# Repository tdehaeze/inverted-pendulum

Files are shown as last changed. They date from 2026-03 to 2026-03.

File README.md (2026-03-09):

# Inverted Pendulum

Active stabilization of an inverted pendulum on a cart, built from a recycled
3D printer (Alfawise U20). The system is controlled by a Teensy 4.1
microcontroller running a 1 kHz feedback loop, and monitored via a PyQt5 GUI.

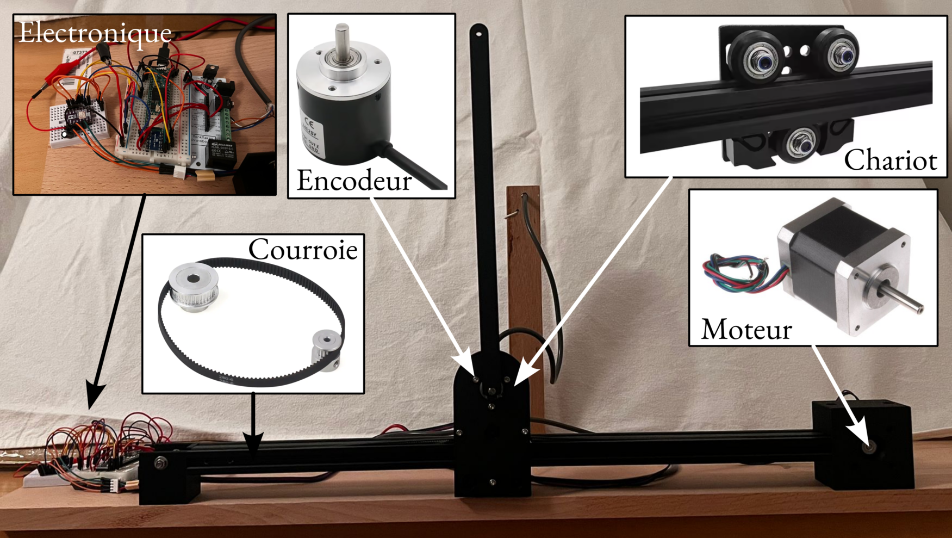
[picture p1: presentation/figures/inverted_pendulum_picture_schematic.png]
System overview


## Repository Structure

```
teensy/     Embedded firmware (PlatformIO / Arduino)
model/      Python simulation and control design
gui/        Real-time control interface (PyQt5)
tools/      Data capture and analysis scripts
data/       Recorded experiment CSV files
figs/       Generated figures
docs/       Hardware datasheets
```

## Hardware

| Component | Details |
|---|---|
| Microcontroller | Teensy 4.1 |
| Stepper motor | DRV8825 driver, 32 microsteps, 5 µm/step |
| Pendulum encoder | Quadrature, 4096 steps/rev → 0.088°/step |
| Cart travel | ±200 mm hard stop, ±160 mm soft limit |
| Control rate | 1 kHz (`IntervalTimer`) |

---

## 1 — Teensy Firmware

### Dependencies

- [PlatformIO](https://platformio.org/) (CLI or VS Code extension)
- Encoder library by Paul Stoffregen (declared in `teensy/platformio.ini`)

### Build and Flash

```bash
cd teensy/
pio run -e teensy41                # build only
pio run -e teensy41 -t upload      # build + flash
```

### Serial Monitor

```bash
pio device monitor                 # 115200 baud
```

### Serial Commands

Once the firmware is running, commands can be sent via the GUI or any serial
terminal at 115200 baud:

| Command | Description |
|---|---|
| `MOTOR ON` / `MOTOR OFF` | Enable / disable stepper motor |
| `FB ON` / `FB OFF` | Close / open feedback loop |
| `ZERO CART` | Reset cart position to 0 |
| `ZERO ENC` | Reset pendulum encoder to 0 |
| `VEL <mm/s>` | Open-loop cart velocity |
| `MODE P` / `MODE PD` / `MODE LQR` | Select controller |
| `SET KP <val>` | Proportional gain (SI units) |
| `SET KD <val>` | Derivative gain (SI units) |
| `SET K <k0> <k1> <k2> <k3>` | LQR gain vector [x, ẋ, φ, φ̇] |
| `SET THETA <deg>` | Pendulum angle setpoint |
| `SET X <mm>` | Cart position setpoint |

### Controllers (all gains in SI units)

- **P**: `u = -Kp · φ`
- **PD**: `u = -Kp · φ - Kd · φ̇`
- **LQR**: `u = -K · [x, ẋ, φ, φ̇]`

where `u` is cart acceleration [m/s²] and `φ = θ − π` is the deviation from
the upright position.

---

## 2 — GUI

### Setup (first time)

```bash
cd gui/
python -m venv .venv
source .venv/bin/activate
pip install PyQt5 pyqtgraph pyserial numpy scipy colorama
```

### Run

```bash
source gui/.venv/bin/activate
python gui/program.py
```

Connects to the Teensy at `/dev/ttyACM0`, 115200 baud. The interface provides:

- **Controller panel** — mode selection (P / PD / LQR), gain entry
- **Setpoints panel** — θ_ref and x_ref
- **Motor control** — enable/disable motor and feedback, zero buttons,
  open-loop velocity slider
- **Data panel** — save telemetry to CSV

---

## 3 — Model & Simulation

### Setup (first time)

```bash
cd model/
python -m venv .venv
source .venv/bin/activate
pip install numpy matplotlib scipy control
```

### Run

```bash
source model/.venv/bin/activate
python model/inverted_pendulum.py
```

Generates simulation figures in `figs/`: open-loop responses, P/PD stability
boundaries, LQR and LQG results.

### System Model

Linearized equations of motion around the upright position (φ = θ − π ≈ 0):

```
D · φ̈ + c · φ̇ − mgl · φ = ml · u
```

State-space form with **X = [x, ẋ, φ, φ̇]**, input **u = ẍ** [m/s²]:

```
Ẋ = A·X + B·u
```

Parameters identified from free-response measurement (`tools/fit.py`):

| Parameter | Symbol | Value |
|---|---|---|
| Pendulum mass | m | 0.1 kg |
| Pendulum length (half) | l | 0.326 m |
| Friction coefficient | c | 3.4 × 10⁻⁴ N·m·s/rad |

---

## 4 — Tools

All tools use the GUI virtual environment:

```bash
source gui/.venv/bin/activate
```

### Capture telemetry

```bash
python tools/capture.py                          # 10 s → data/data.csv
python tools/capture.py -d 30 -o data/run.csv   # 30 s to custom file
python tools/capture.py -d 10 -p /dev/ttyACM1   # custom port
```

### Fit model parameters

```bash
python tools/fit.py data/free_response.csv --mass 0.1
```

Fits pendulum length `l` and friction `c` to a free-response recording using
Nelder-Mead optimisation. Saves `figs/<name>_data.png` and
`figs/<name>_fit.png`.

Options: `--mass`, `--t-start`, `--l-init`, `--c-init`

### Plot experiment

```bash
python tools/plot_experiment.py data/run.csv
python tools/plot_experiment.py data/run.csv --ylim-phi 5 --ylim-x 100
python tools/plot_experiment.py data/run.csv --split --zero-at-feedback
python tools/plot_experiment.py data/run.csv --all --detrend-x --no-shading
```

Plots the last closed-loop segment of a CSV recording (φ and cart position).

| Option | Description |
|---|---|
| `--all` | Plot entire file instead of last segment |
| `--margin <s>` | Time margin before/after segment (default: 1 s) |
| `--margin-after <s>` | Override margin after segment |
| `--ylim-phi <deg>` | ±limit on φ axis |
| `--ylim-x <mm>` | ±limit on cart position axis |
| `--detrend-x` | Remove mean from cart position |
| `--no-shading` | Hide green feedback-on shading |
| `--split` | Save separate `_phi.png` and `_x.png` figures (half-width) |
| `--zero-at-feedback` | Set t = 0 at feedback start |

### Plot stability

```bash
python tools/plot_stability.py data/run.csv --duration 20
python tools/plot_stability.py data/run.csv --duration 30 --ylim-phi 3 --ylim-x 10
```

Plots the last N seconds of a recording to visualise closed-loop stability.

---

## 5 — Typical Workflow

### Initial setup

1. Flash the firmware: `cd teensy && pio run -e teensy41 -t upload`
2. Start the GUI: `source gui/.venv/bin/activate && python gui/program.py`
3. Enable the motor (**Motor ON**), zero the cart and encoder

### Identify model parameters

1. Place pendulum hanging freely (θ ≈ 0°)
2. Give it a small push and record 10–50 s of free oscillation:
   ```bash
   python tools/capture.py -d 50 -o data/free_response.csv
   ```
3. Fit the model:
   ```bash
   python tools/fit.py data/free_response.csv --mass <m_kg>
   ```
4. Update `PendulumParameters` in `model/inverted_pendulum.py` with the
   fitted values

### Tune and run a controller

1. In the GUI, set **MODE PD** and enter Kp / Kd
2. Bring the pendulum near upright and press **FB ON**
3. Save data with **Save CSV**, then analyse:
   ```bash
   python tools/plot_experiment.py data/<run>.csv --split --zero-at-feedback --ylim-phi 5
   ```

### LQR synthesis

```bash
source model/.venv/bin/activate
python model/inverted_pendulum.py   # prints K vector
```

Enter the resulting K in the GUI under **LQR gains**, switch to **MODE LQR**.

---

## 6 — Demonstrations

### System identification — free oscillation response

https://github.com/user-attachments/assets/c429f093-9673-4762-9016-3ae0847f1448

Free oscillation of the pendulum used to identify the model parameters (length $l$, friction coefficient $c$) via least-squares fitting.

---

### PD control — stabilization

https://github.com/user-attachments/assets/20660b4e-676f-49f9-a179-077e801f84ba

Pendulum stabilized at the upright position using a PD controller. The pendulum angle is regulated but the cart drifts over time.

---

### PD control — damping only

https://github.com/user-attachments/assets/50c5440a-8c1c-4f35-89b8-adac04f1c9ea

Controller acting primarily as a damper, slowing down the pendulum dynamics without full stabilization.

---

### LQR — low gain

https://github.com/user-attachments/assets/f3a342e8-8304-4135-925a-9110caccaa7a

LQR with low state weighting: the controller stabilizes the pendulum with slow, smooth corrections.

---

### LQR — high gain

https://github.com/user-attachments/assets/20061e29-bd0e-405f-b965-5c8c7497c029

LQR with higher gain: faster correction of angle and cart position deviations.

---

### LQR — higher gain

https://github.com/user-attachments/assets/9aa5e672-d7a8-477d-8541-99d07afa2d80

Wide view of the same higher-gain LQR configuration, showing simultaneous control of both angle and cart position.

---

### LQR — changing cart position setpoint

https://github.com/user-attachments/assets/6f5ab4ad-76a4-4d68-8fe5-9a155da7ca44

LQR controller tracking a step change in the cart position setpoint $x_\mathrm{ref}$, while keeping the pendulum upright.

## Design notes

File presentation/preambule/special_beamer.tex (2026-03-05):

%%%%%%%%%%%%%%%%%%%%%%%%%%%%%%%%%%%%%%%%%
% Beamer Presentation
% LaTeX Template
% Version 1.0 (10/11/12)
%
% This template has been downloaded from:
% http://www.LaTeXTemplates.com
%
% License:
% CC BY-NC-SA 3.0 (http://creativecommons.org/licenses/by-nc-sa/3.0/)
%
%%%%%%%%%%%%%%%%%%%%%%%%%%%%%%%%%%%%%%%%%

%----------------------------------------------------------------------------------------
%	PACKAGES AND THEMES
%----------------------------------------------------------------------------------------

\mode<presentation> {

% The Beamer class comes with a number of default slide themes
% which change the colors and layouts of slides. Below this is a list
% of all the themes, uncomment each in turn to see what they look like.

%\usetheme{default}
%\usetheme{AnnArbor}
%\usetheme{Antibes}
%\usetheme{Bergen}
%\usetheme{Berkeley}
%\usetheme{Berlin}
%\usetheme{Boadilla}
%\usetheme{CambridgeUS}
%\usetheme{Copenhagen}
%\usetheme{Darmstadt}
%\usetheme{Dresden}
%\usetheme{Frankfurt}
%\usetheme{Goettingen}
%\usetheme{Hannover}
%\usetheme{Ilmenau}
%\usetheme{JuanLesPins}
%\usetheme{Luebeck}
%\usetheme{Madrid}		
%\usetheme{Malmoe}
%\usetheme{Marburg}
%\usetheme{Montpellier}
%\usetheme{PaloAlto}
%\usetheme{Pittsburgh}
%\usetheme{Rochester}
%\usetheme{Singapore}
%\usetheme{Szeged}
\usetheme{Warsaw}

% As well as themes, the Beamer class has a number of color themes
% for any slide theme. Uncomment each of these in turn to see how it
% changes the colors of your current slide theme.

%\usecolortheme{albatross}
%\usecolortheme{beaver}
%\usecolortheme{beetle}
%\usecolortheme{crane}
%\usecolortheme{dolphin}
%\usecolortheme{dove}
%\usecolortheme{fly}
%\usecolortheme{lily}
%\usecolortheme{orchid}
%\usecolortheme{rose}
%\usecolortheme{seagull}
%\usecolortheme{seahorse}
\usecolortheme{whale}
%\usecolortheme{wolverine}

%\setbeamertemplate{footline} % To remove the footer line in all slides uncomment this line
%\setbeamertemplate{footline}[frame number] % To replace the footer line in all slides with a simple slide count uncomment this line

%\setbeamertemplate{navigation symbols}{} % To remove the navigation symbols from the bottom of all slides uncomment this line

% \setbeamercovered{transparent} % Fait apparaître les animations en grisé (utile pour la conception, mais peut être commenté lors de la remise du document final)

% Pour utiliser une police à empattements partout
\usefonttheme{serif}

% Pour rajouter la numérotation des frames dans les pieds de page
\newcommand*\oldmacro{}%
\let\oldmacro\insertshorttitle%
\renewcommand*\insertshorttitle{%
  \oldmacro\hfill%
  \insertframenumber\,/\,\inserttotalframenumber}

}

\usepackage{graphicx} % Allows including images
\usepackage{booktabs} % Allows the use of \toprule, \midrule and \bottomrule in tables

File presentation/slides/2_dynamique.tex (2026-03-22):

\section{Étude de la dynamique du Pendule Inversé}

\begin{frame}
\frametitle{Étude de la dynamique}
\framesubtitle{Présentation du système}

\begin{figure}
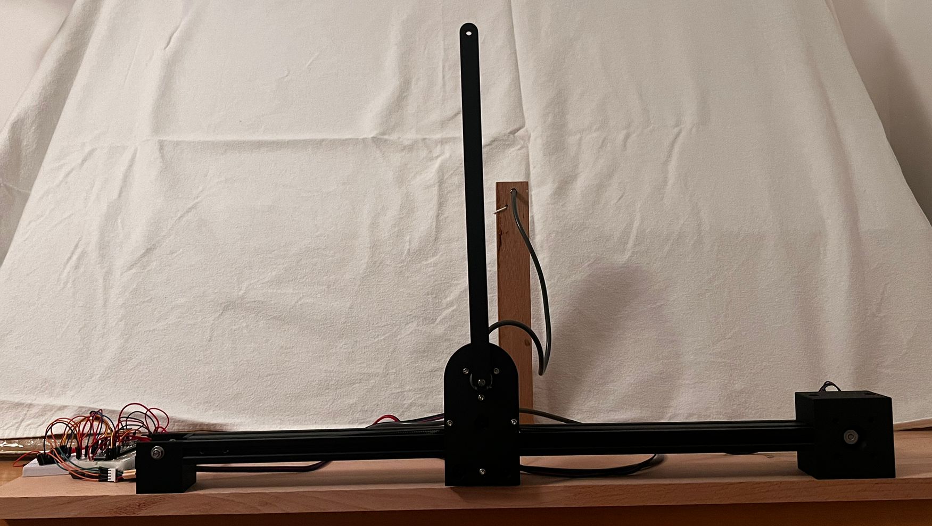
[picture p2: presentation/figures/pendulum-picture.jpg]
    \only<1>{}%
    \only<2>{}
\end{figure}

\end{frame}

%%%%%%%%%%%%%%%%%%%%%%%%%%%%%%%%%%%%%%%%%%%%%%%%

\begin{frame}
\frametitle{Étude de la dynamique}
\framesubtitle{Modèle et Équations de la dynamique}

\begin{columns}[T]

%--- Colonne gauche : schéma ---
\begin{column}{0.4\textwidth}
\begin{center}
\begin{tikzpicture}[>=Stealth, scale=0.8]

  % Ground
  \fill[pattern=north east lines, pattern color=gray!60] (-1.5,-0.18) rectangle (1.5,0);
  \draw[thick] (-1.5,0) -- (1.5,0);

  % Wheels
  \draw[thick, fill=white] (-0.45, 0.15) circle [radius=0.15];
  \draw[thick, fill=white] ( 0.45, 0.15) circle [radius=0.15];

  % Cart body
  \draw[thick, fill=gray!20, rounded corners=3pt]
    (-0.8, 0.15) rectangle (0.8, 0.75);

  % Pivot
  \coordinate (O) at (0, 0.75);
  \fill (O) circle [radius=0.1];

  % Pendulum (theta = 150 deg from downward, 30 deg from upright)
  \coordinate (tip) at ($(O) + ({0.5*3.0}, {0.866*3.0})$);

  % Dashed verticals
  \draw[dashed, gray] (O) -- ++(0,  3.5);
  \draw[dashed, gray] (O) -- ++(0, -0.9);

  % Angle arc (CCW from downward to rod, through right side)
    \draw[->, thick, red!60!black] ($(O)+(-90:0.7)$) arc[start angle=-90, end angle=60, radius=0.7] node[near end, right] {$\theta$};

  % Pendulum rod
  \draw[line width=2pt] (O) -- node[midway, right=6pt] {$m$} (tip);

  % Length arrow
  \draw[<->, thin]
    ($(O)   + ({-0.866*0.35}, {0.5*0.35})$)
    -- node[left=2pt] {$l$}
    ($(tip) + ({-0.866*0.35}, {0.5*0.35})$);

  % Tip dot
  \fill (tip) circle [radius=0.05];

  % Acceleration arrow
  \draw[->, thick, blue!60!black]
    (0.85, 0.44) -- ++(1.0, 0) node[right] {$u = \ddot{x}$};

\end{tikzpicture}
\end{center}
\end{column}

%--- Colonne droite : équations ---
\begin{column}{0.58\textwidth}
  \vspace{0.5cm}
  \textbf{Équation du mouvement :}
  \begin{equation*}
      \frac{1}{3}ml^2\,\ddot{\theta} + c\,\dot{\theta} + \underbrace{mgl\sin\theta + ml\cos\theta\cdot u}_{\text{non linéaire}} = 0
  \end{equation*}

    \only<2>{%

    \vfill
    \begin{center}
    \begin{tcolorbox}[
        width=0.9\linewidth,
        colback=blue!5,
        colframe=blue!50!black,
        arc=4pt,
        boxrule=1pt,
        fontupper=\large
    ]
        Linéarisation pour étude de la dynamique et contrôle
    \end{tcolorbox}
    \end{center}
    \vfill
    }%
\end{column}

\end{columns}

\end{frame}

%%%%%%%%%%%%%%%%%%%%%%%%%%%%%%%%%%%%%%%%%%%%%%%%

\begin{frame}
\frametitle{Étude de la dynamique}
\framesubtitle{Linéarisations et Réponses du système}

\begin{columns}[T]

\begin{column}{0.48\textwidth}
  \uncover<1->{%
  \centering\textbf{Position basse} ($\theta \approx 0$)
  \begin{equation*}
      \frac{1}{3}ml^2\,\ddot{\theta} + c\,\dot{\theta} + mgl\,\theta = -mlu
  \end{equation*}
  $\Rightarrow$ Oscillations amorties

  \begin{figure}
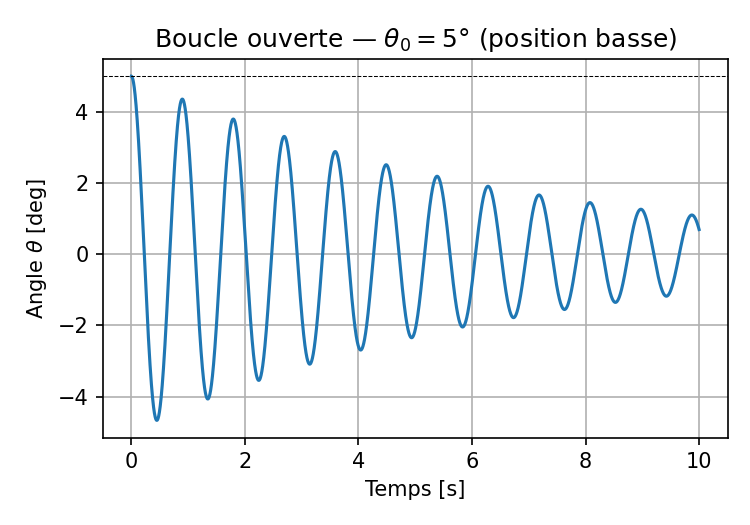
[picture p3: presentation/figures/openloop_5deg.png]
      
  \end{figure}
  }%
\end{column}

\begin{column}{0.48\textwidth}
  \uncover<2->{%
  \centering\textbf{Position haute} ($\varphi = \theta - \pi \approx 0$)
  \begin{equation*}
      \frac{1}{3}ml^2\,\ddot{\varphi} + c\,\dot{\varphi} - mgl\,\varphi = mlu
  \end{equation*}
  $\Rightarrow$ Divergence exponentielle

  \begin{figure}
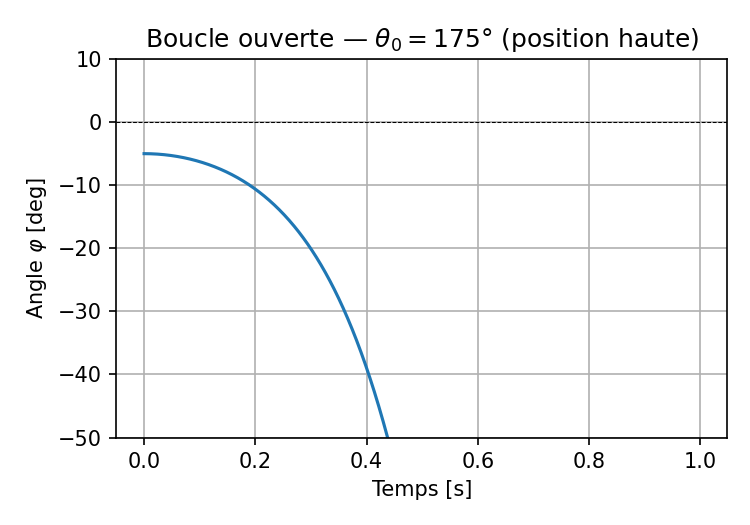
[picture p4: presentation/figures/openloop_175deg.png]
      
  \end{figure}
  }%
\end{column}

\end{columns}

\end{frame}

%%%%%%%%%%%%%%%%%%%%%%%%%%%%%%%%%%%%%%%%%%%%%%%%

\begin{frame}
\frametitle{Étude de la dynamique}
\framesubtitle{Comparaison modèle / expérience}

\begin{center}
\begin{tikzpicture}[>=Stealth,
    box/.style={draw, rounded corners=4pt, fill=blue!8, text width=2.4cm,
                align=center, minimum height=1.2cm, font=\small},
    arr/.style={->, thick, blue!60!black}
  ]

  \node[box] (meas) {Mesure de la\\réponse\\expérimentale};
  \uncover<2->{%
      \node[box, right=1.4cm of meas] (opt) {Optimisation\\des paramètres\\du modèle (Python)};
    \node[box, right=1.0cm of opt]  (res) {Paramètres\\identifiés\\$l,\ c$};
    \draw[arr] (meas) --node[midway, above]{Données}node[midway, below]{$m = 30\,g$} (opt);
    \draw[arr] (opt)  -- (res);
  }

\end{tikzpicture}
\end{center}

\vspace{0.2cm}

\begin{figure}
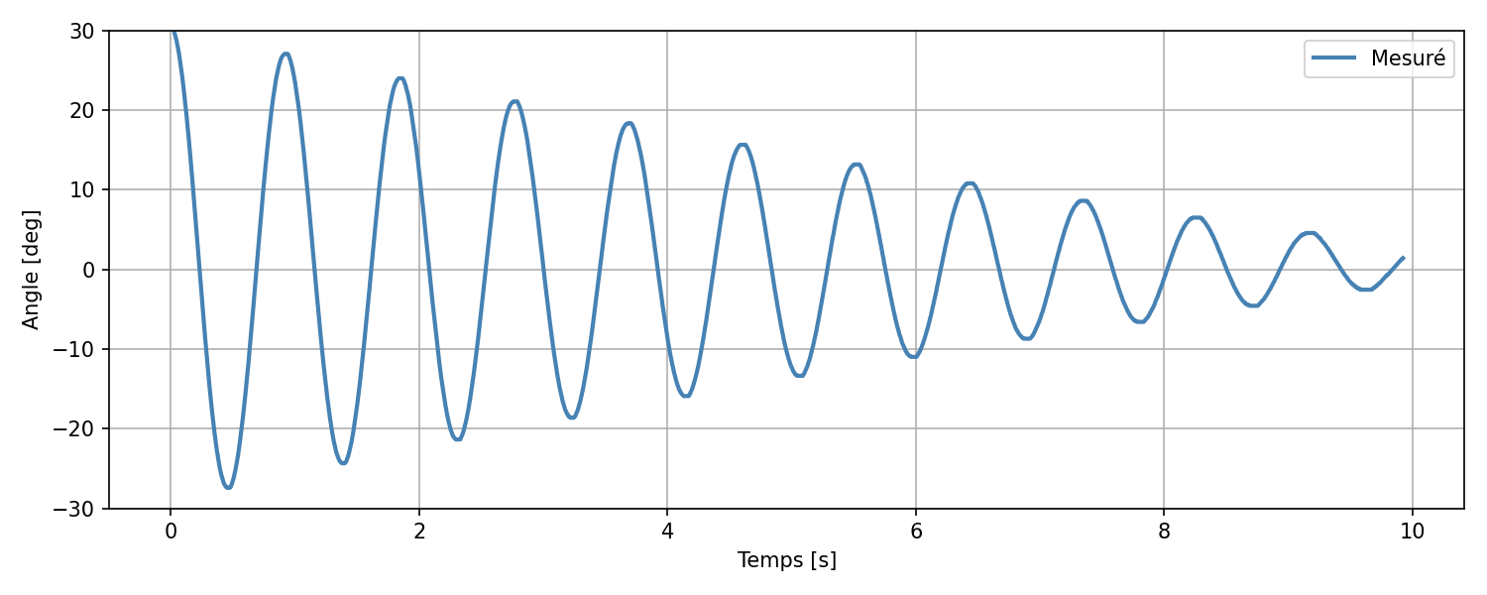
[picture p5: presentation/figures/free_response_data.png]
  \only<1>{}%
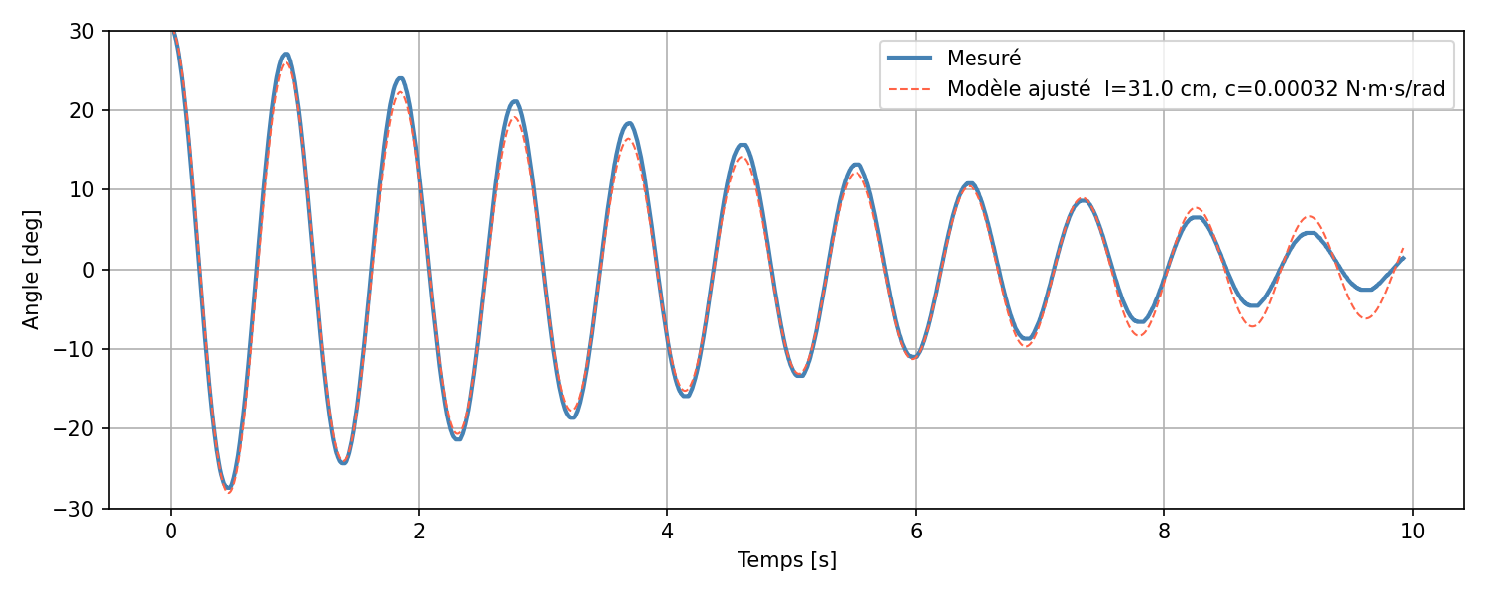
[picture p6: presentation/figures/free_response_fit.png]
  \only<2>{}%
\end{figure}

\end{frame}

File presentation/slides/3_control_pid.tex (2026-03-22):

% Le titre de la partie
\section{Stabilisation de la dynamique par contrôle PD}

%%%%%%%%%%%%%%%%%%%%%%%%%%%%%%%%%%%%%%%%%%%%%%%%

\begin{frame}
\frametitle{Contrôle PD}
\framesubtitle{Schéma block du contrôle du pendule inversé}

\begin{center}
\begin{tikzpicture}[>=Stealth, auto,
    block/.style={draw, rectangle, rounded corners=3pt, fill=blue!8,
                  minimum height=1.0cm, minimum width=2.2cm,
                  align=center, font=\small},
    sum/.style  ={draw, circle, minimum size=0.65cm, inner sep=0pt},
    node distance=0pt
  ]

  % Nodes
  \node[sum] (sum) {};
  \node[block, right=1.2cm of sum] (pd)    {Contrôleur\\PD};
  \node[block, right=1.8cm of pd]  (plant) {Pendule\\inversé};

  % Summing junction +/-
  \node[font=\footnotesize, below left=2pt and 2pt of sum] {$-$};

  % Input: theta_ref
  \draw[->] (sum.west) ++(-1.5,0) node[above right] {$\theta_\mathrm{ref} = \pi$} -- (sum.west);

  % sum -> PD
    \draw[->] (sum.east) -- node[midway, above] {$\varepsilon_\theta(t)$} (pd.west);

  % PD -> plant
    \draw[->] (pd.east) -- node[midway, above] {$u(t) = \ddot{x}(t)$} (plant.west);

  % plant -> output
    \draw[->] (plant.east) node[above right] {$\theta(t)$} -| ++(1.0, -1.0) -| (sum.south);
\end{tikzpicture}
\end{center}

\vspace{0.3cm}

\[
  u(t) = \underbrace{k_p \cdot \varepsilon_\theta(t)}_{\text{Proportionnel}}
        + \underbrace{k_d \cdot \frac{\mathrm{d} \varepsilon_\theta(t)}{\mathrm{d} t}}_{\text{Dérivé}}
\]

\end{frame}

%%%%%%%%%%%%%%%%%%%%%%%%%%%%%%%%%%%%%%%%%%%%%%%%

\begin{frame}
\frametitle{Contrôle PD}
\framesubtitle{Contrôleur Proportionnel}

Avec $u = -k_p\,\varphi$, l'équation linéarisée devient :
\[
    \frac{1}{3}ml^2\,\ddot{\varphi} + c\,\dot{\varphi} + (ml\,k_p - mgl)\,\varphi = 0
\]
    Stable si $\Delta = c^2 - 4 \frac{1}{3}ml^2 \cdot (ml\,k_p - mgl) > 0$, donc si $k_p > k_{p,c}$, avec
    \[
    k_{p,c} = g + \frac{3 c^2}{4 m^2l^3} \approx 9.8
\]

% \vspace{0.2cm}

\begin{columns}[T]
  \begin{column}{0.48\textwidth}
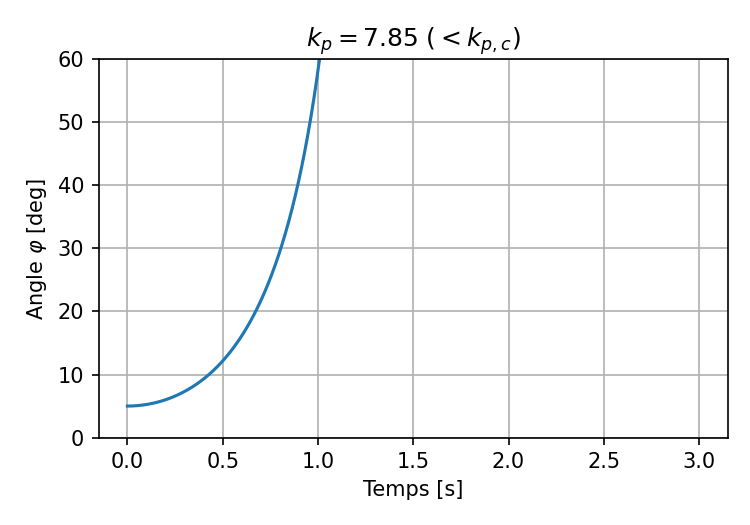
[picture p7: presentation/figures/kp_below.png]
    
  \end{column}
  \begin{column}{0.48\textwidth}
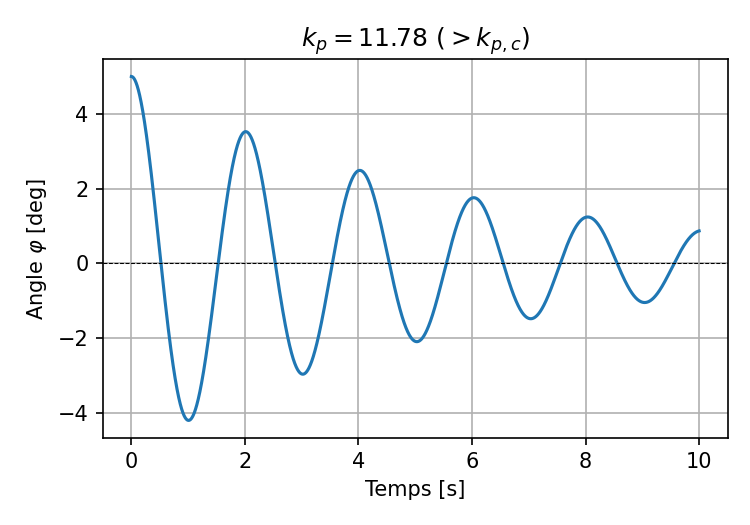
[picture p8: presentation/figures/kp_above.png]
    
  \end{column}
\end{columns}

\end{frame}

%%%%%%%%%%%%%%%%%%%%%%%%%%%%%%%%%%%%%%%%%%%%%%%%

\begin{frame}
\frametitle{Contrôle PD}
\framesubtitle{Contrôleur Dérivatif}

% Expliquer comment le contrôleur derivatif modifie la dynamique du système: ça ajoute de l'amortissement.
% Ca peut être important pour le confort sur un segway par exemple.

Avec $u = -k_p\,\varphi - k_d\,\dot{\varphi}$, l'équation linéarisée devient :
\[
    \frac{1}{3}ml^2\,\ddot{\varphi} + (c + ml\,k_d)\,\dot{\varphi} + (ml\,k_p - mgl)\,\varphi = 0
\]
Amortissement critique:
    \[
    k_{d,c} = \frac{1}{ml}\!\left(2\sqrt{\frac{1}{3}ml^2\,(ml\,k_p - mgl)} - c\right) \approx 1.2
\]

\begin{figure}
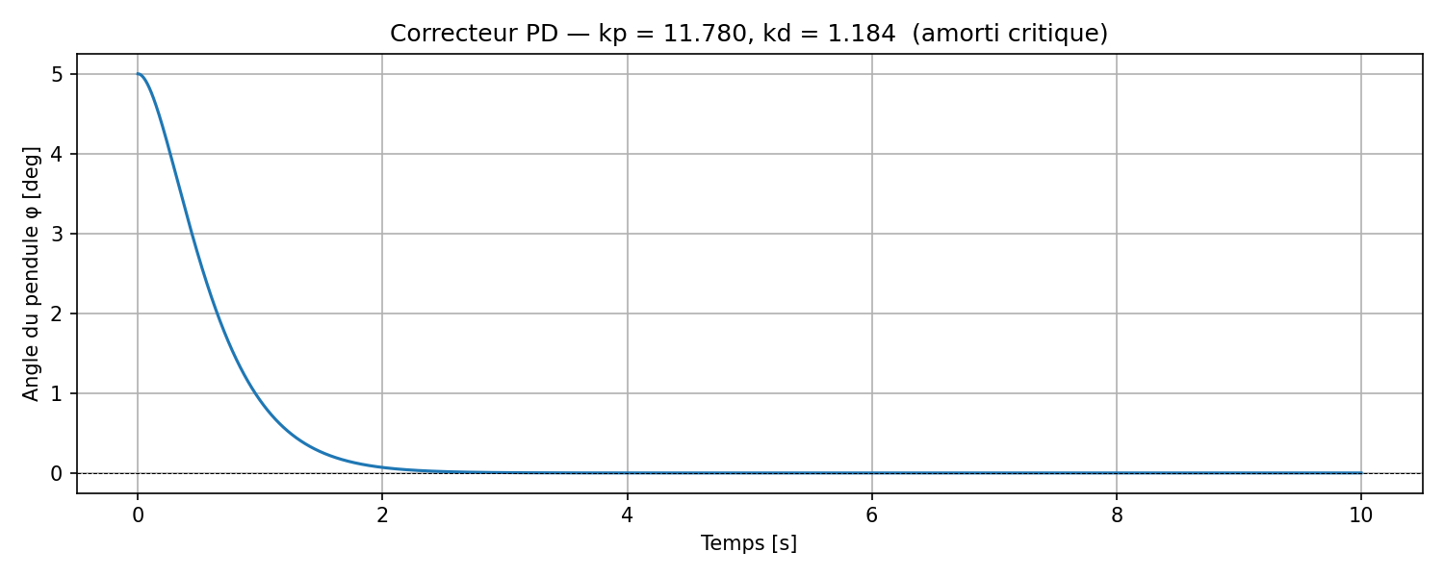
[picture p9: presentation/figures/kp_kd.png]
    
\end{figure}

\end{frame}

%%%%%%%%%%%%%%%%%%%%%%%%%%%%%%%%%%%%%%%%%%%%%%%%

\begin{frame}
\frametitle{Contrôle PD}
\framesubtitle{Résultats expérimentaux}

\begin{columns}[T]
  \begin{column}{0.48\textwidth}
    % Steps 1-2: experimental plots
    \uncover<1->{%
      {\scriptsize Résultats expérimentaux — $k_p = 12$, $k_d = 1$}\\
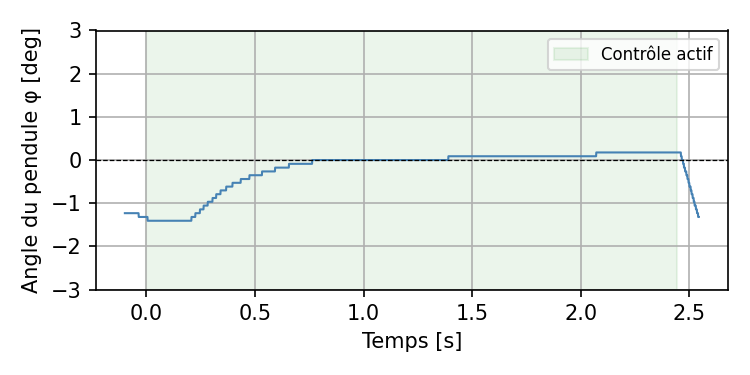
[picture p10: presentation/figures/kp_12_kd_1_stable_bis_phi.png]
      \\[2pt]
      \uncover<2->{%
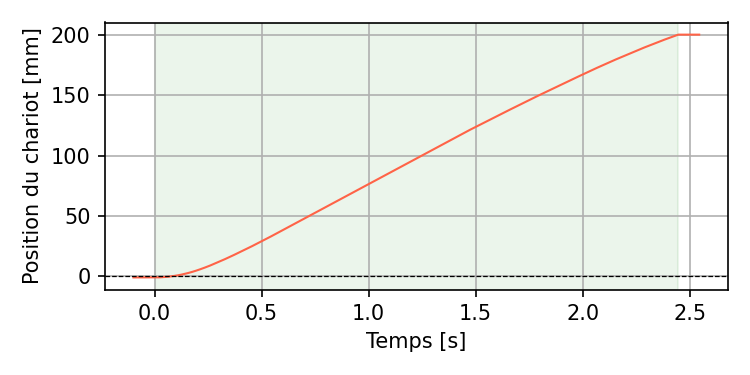
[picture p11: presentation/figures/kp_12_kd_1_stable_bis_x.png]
          %
      }%
    }%
  \end{column}
  \begin{column}{0.48\textwidth}
    % Steps 3-7: photos
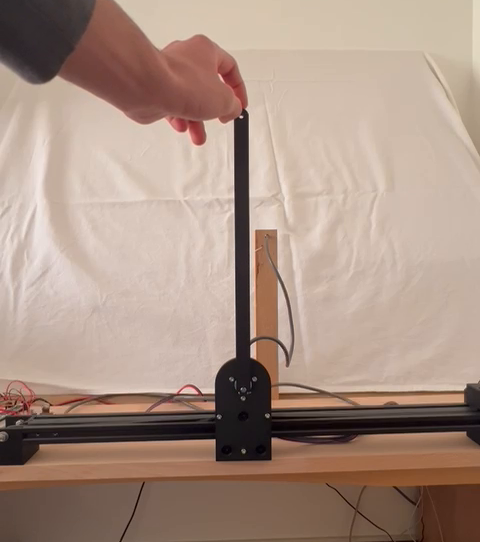
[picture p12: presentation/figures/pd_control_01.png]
    \only<3>{}%
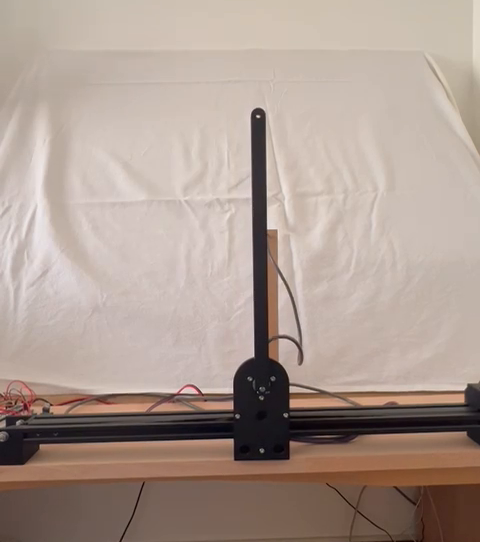
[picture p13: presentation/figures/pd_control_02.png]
    \only<4>{}%
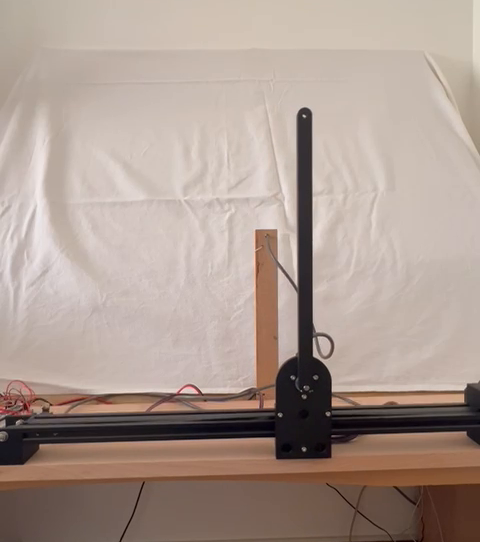
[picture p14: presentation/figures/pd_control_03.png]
    \only<5>{}%
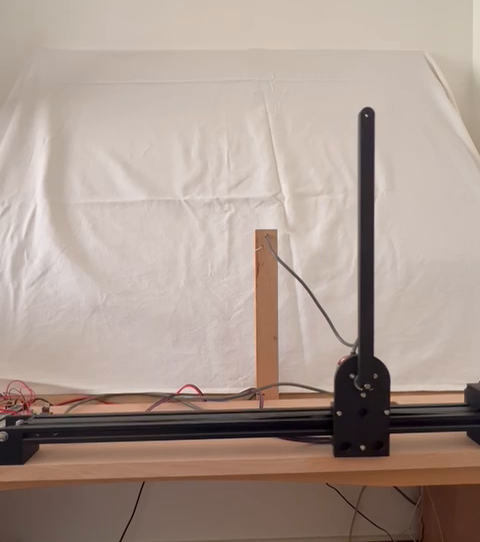
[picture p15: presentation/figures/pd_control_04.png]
    \only<6>{}%
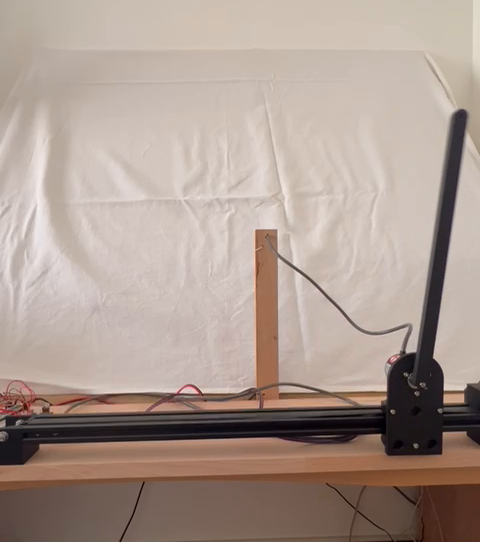
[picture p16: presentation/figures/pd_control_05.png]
    \only<7>{}%
    % Step 8: simulation
    \only<8>{%
        Même comportement en simulation:
        $\phi$ est correctement stabilisé, mais le chariot n'est pas stable.

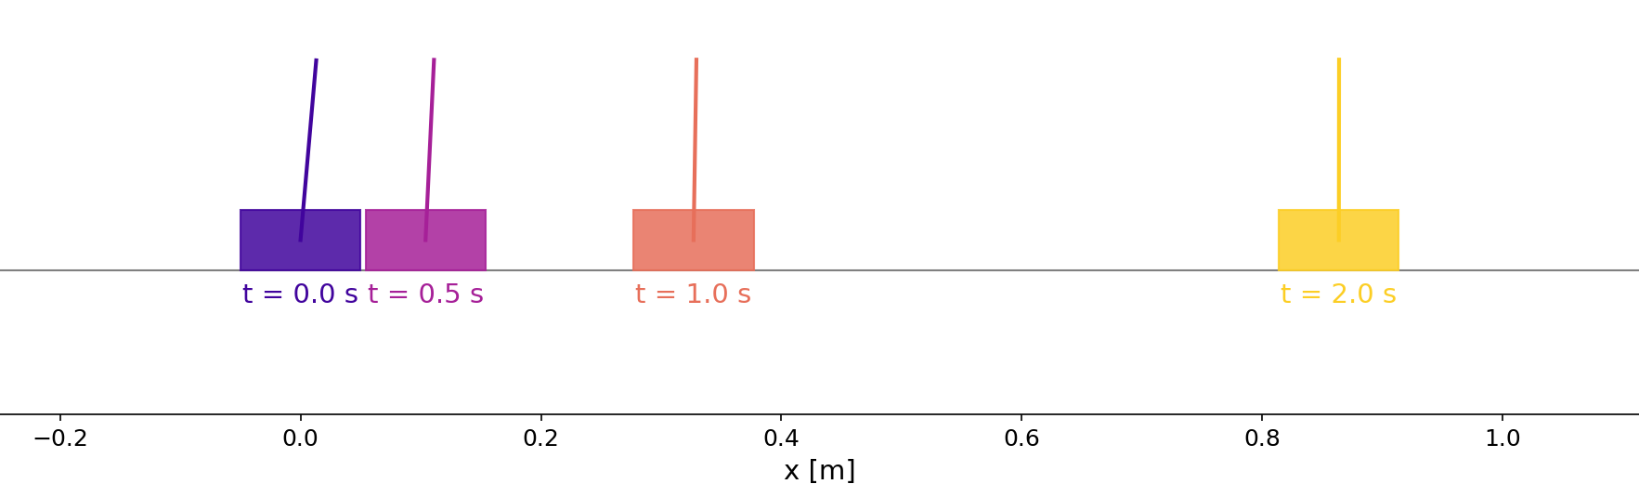
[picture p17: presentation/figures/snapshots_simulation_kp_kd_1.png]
        \\[2pt]
        {\scriptsize Résultats de simulation — $k_p = 12$, $k_d = 1$}

        \vspace{1em}

        Pour contrôler à la fois $\phi$ et $x$, le contrôleur PD n'est pas adapté.
    }%
  \end{column}
\end{columns}

\end{frame}

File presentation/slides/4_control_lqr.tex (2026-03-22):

\section{Stabilisation de la dynamique par contrôle LQ}

%%%%%%%%%%%%%%%%%%%%%%%%%%%%%%%%%%%%%%%%%%%%%%%%

\begin{frame}
\frametitle{Contrôle LQ}
\framesubtitle{Modèle d'état — Commande par retour d'état}

Modèle par représentation d'états:
\[
    \mathbf{X} =
    \begin{pmatrix} x \\ \dot{x} \\ \varphi \\ \dot{\varphi} \end{pmatrix}, \quad
        \dot{\mathbf{X}} = A\mathbf{X} + B u, \quad
        A = \begin{pmatrix}
            0 & 1 & 0 & 0 \\
            0 & 0 & 0 & 0 \\
            0 & 0 & 0 & 1 \\
            0 & 0 & \tfrac{3g}{l} & -\tfrac{3c}{ml^2}
        \end{pmatrix}, \quad
        B = \begin{pmatrix} 0 \\ 1 \\ 0 \\ \tfrac{3}{l} \end{pmatrix}
        \]

\vspace{1em}

Commande par retour d'état:

\vspace{1em}

\begin{tikzpicture}[>=Stealth, auto,
    block/.style={draw, rectangle, rounded corners=3pt, fill=blue!8,
                  minimum height=0.9cm, minimum width=2.0cm,
                  align=center, font=\small},
    sum/.style={draw, circle, minimum size=0.6cm, inner sep=0pt},
    node distance=0pt
  ]
  \node[sum] (sum) {};
  \node[font=\footnotesize, below left=0pt of sum] {$-$};
  \node[block, right=1.0cm of sum] (K) {$\mathbf{K}$};
  \node[block, right=1.0cm of K]   (plant) {Pendule\\inversé};

  % X_ref input
  \draw[->] (sum.west) ++(-1.2,0) node[above right] {$\mathbf{X}_\mathrm{ref}$} -- (sum.west);

  % sum -> K
  \draw[->] (sum.east) -- (K.west);

  % K -> plant
  \draw[->] (K.east) -- node[midway, above] {$u(t)$} (plant.west);

  % plant output + feedback
  \draw[->] (plant.east) node[above right] {$\mathbf{X}(t)$} -| ++(0.7,-1.0) -| (sum.south);
\end{tikzpicture}

\vspace{0.3cm}
\[
  u(t) = \mathbf{K}\,\bigl(\mathbf{X}_\mathrm{ref} - \mathbf{X}(t)\bigr), \quad
  \mathbf{K} = \begin{bmatrix} k_x & k_{\dot x} & k_\varphi & k_{\dot\varphi} \end{bmatrix}
\]

\end{frame}

%%%%%%%%%%%%%%%%%%%%%%%%%%%%%%%%%%%%%%%%%%%%%%%%

\begin{frame}
\frametitle{Contrôle LQ}
\framesubtitle{Choix de la matrice de retour d'état}

Minimisation d'un critère quadratique :
\[
  J = \int_0^\infty \!\bigl(\mathbf{X}^\top Q\,\mathbf{X} + u^\top R\,u\bigr)\,\mathrm{d}t
\]
\begin{itemize}
  \item $Q \succeq 0$ pondère les états: $Q = \mathrm{diag}(q_x,\, q_{\dot x},\, q_\varphi,\, q_{\dot\varphi})$
  \item $R > 0$ pondère l'effort de commande
\end{itemize}

\vspace{0.3cm}
$\mathbf{K}$ est obtenu par résolution de l'équation algébrique de Riccati :
\[
  A^\top P + PA - PBR^{-1}B^\top P + Q = 0
  \ \Longrightarrow\ 
  \boxed{\mathbf{K} = R^{-1}B^\top P}
\]

\vspace{1em}

\textbf{Exemple} $q_x = 100$, $q_\varphi = 1$, $R = 1$ $\Longrightarrow$ $\mathbf{K} = \begin{bmatrix} -10.0 & -8.7 & 46.9 & 9.8 \end{bmatrix}$

\end{frame}

%%%%%%%%%%%%%%%%%%%%%%%%%%%%%%%%%%%%%%%%%%%%%%%%

\begin{frame}
\frametitle{Contrôle LQ}
\framesubtitle{Simulation}

\begin{columns}[T]
  \begin{column}{0.5\textwidth}
    \centering
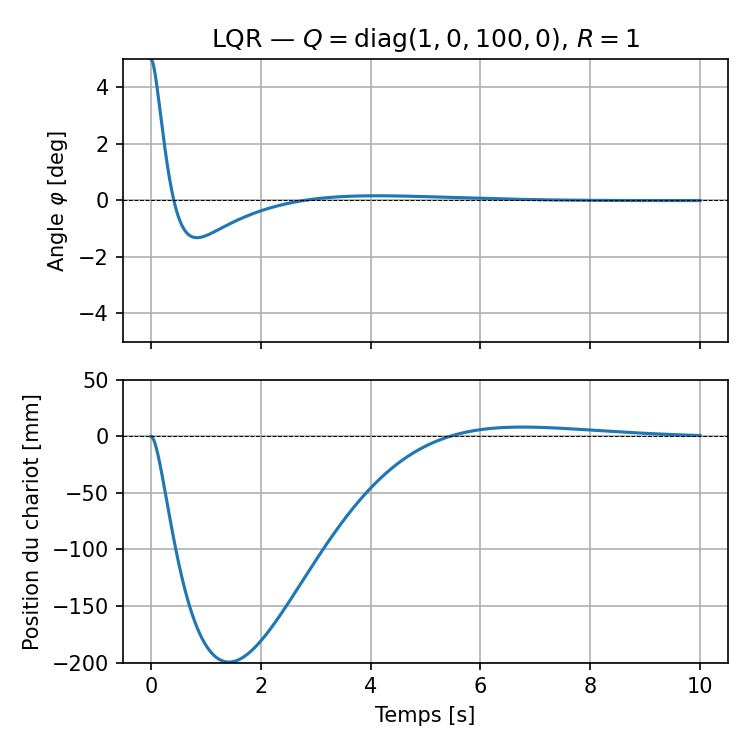
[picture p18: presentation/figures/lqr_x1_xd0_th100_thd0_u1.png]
    \\[2pt]
    {\scriptsize Pondération forte sur $\varphi$: $q_x = 1$, $q_\varphi = 100$}
  \end{column}
  \begin{column}{0.5\textwidth}
    \centering
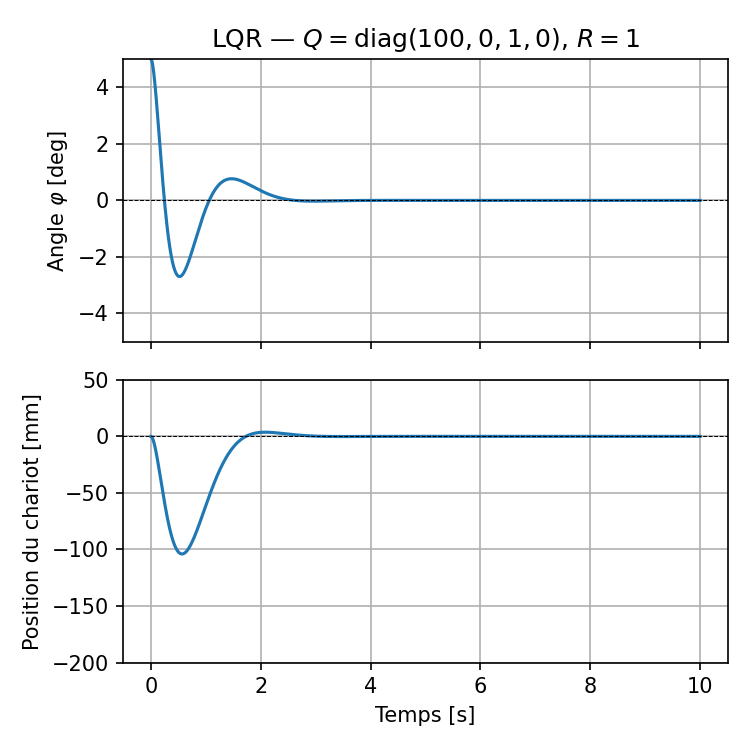
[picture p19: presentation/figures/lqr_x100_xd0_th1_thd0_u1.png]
    \\[2pt]
    {\scriptsize Pondération forte sur $x$: $q_x = 100$, $q_\varphi = 1$}
  \end{column}
\end{columns}

\end{frame}

%%%%%%%%%%%%%%%%%%%%%%%%%%%%%%%%%%%%%%%%%%%%%%%%

\begin{frame}
\frametitle{Contrôle LQ}
\framesubtitle{Résultats Expérimentaux}
\begin{columns}[T]
  \begin{column}{0.7\textwidth}
    \begin{figure}
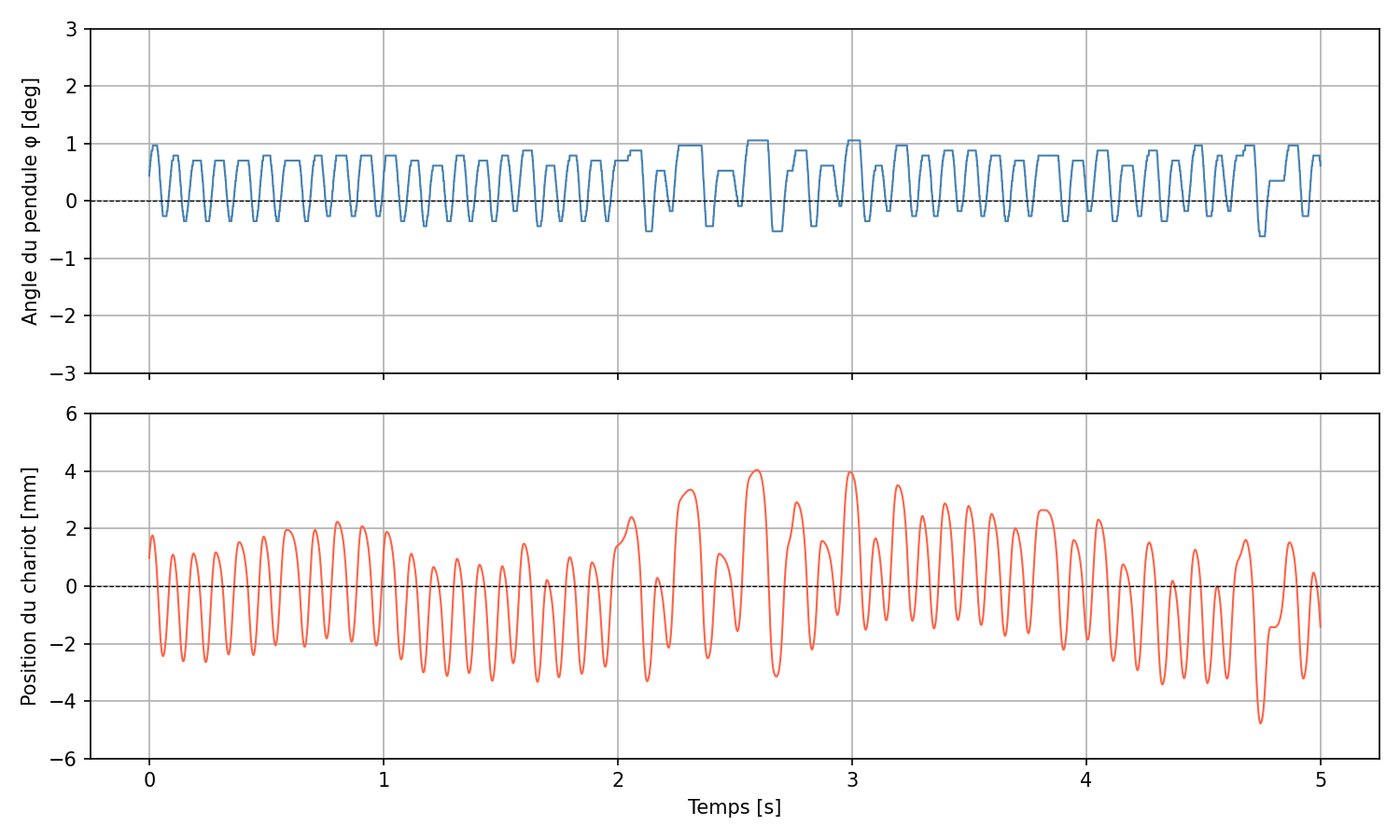
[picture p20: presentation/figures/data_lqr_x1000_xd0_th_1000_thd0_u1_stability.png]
        \\[2pt]
        
        {\scriptsize $\mathbf{K} = [-31.6\ -23.1\ 92.8\ 18.3]$, stabilité observée de $\pm 1\,\text{deg}$, $\pm 4\,mm$}
    \end{figure}
  \end{column}
  \begin{column}{0.3\textwidth}
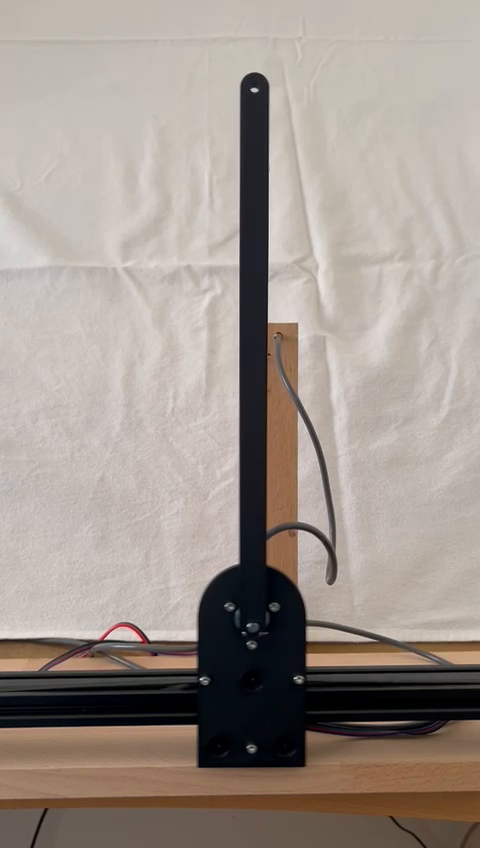
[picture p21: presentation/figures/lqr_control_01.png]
    \only<2>{}%
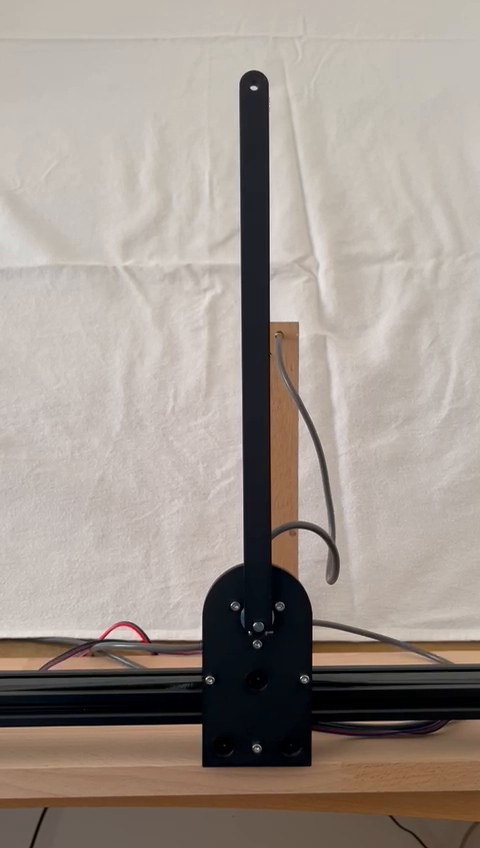
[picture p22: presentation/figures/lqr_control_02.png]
    \only<3>{}%
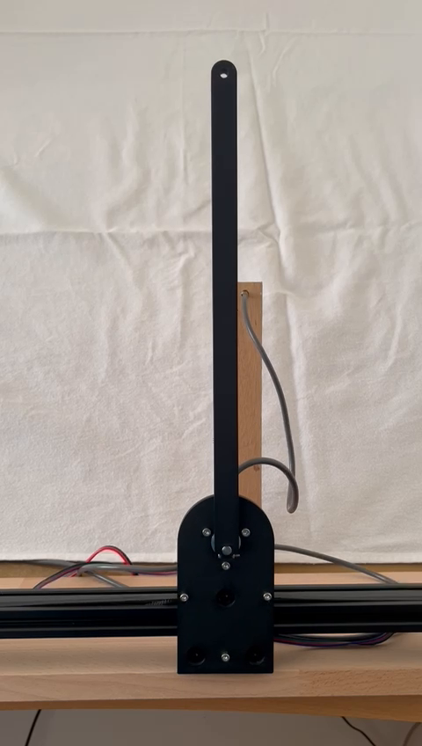
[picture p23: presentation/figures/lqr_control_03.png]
    \only<4>{}%
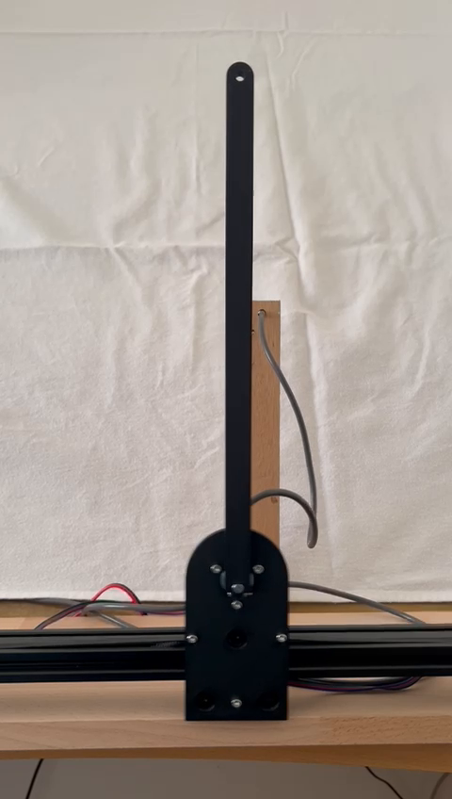
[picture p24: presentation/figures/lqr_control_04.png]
    \only<5>{}%
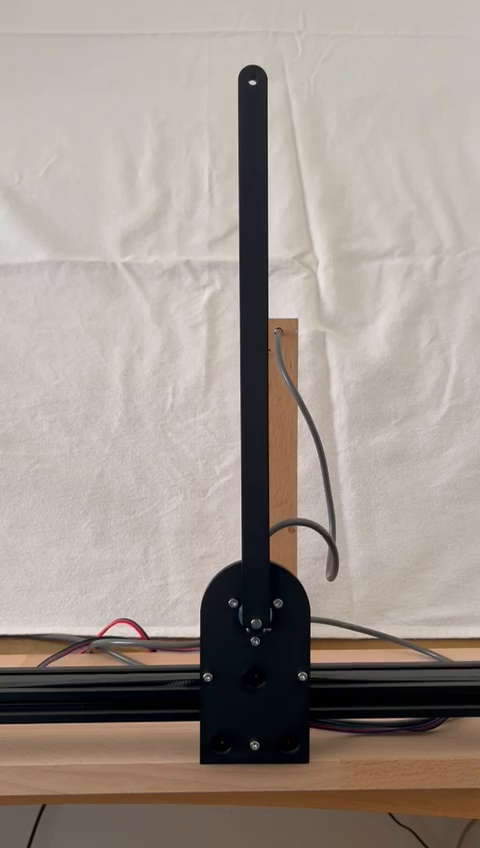
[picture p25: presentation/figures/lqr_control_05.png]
    \only<6>{}%
  \end{column}
\end{columns}
\end{frame}

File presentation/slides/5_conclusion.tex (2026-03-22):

% Le titre de la partie
\section{Conclusion}

%%%%%%%%%%%%%%%%%%%%%%%%%%%%%%%%%%%%%%%%%%%%%%%%
% Première diapo avec un exemple de tableau
%%%%%%%%%%%%%%%%%%%%%%%%%%%%%%%%%%%%%%%%%%%%%%%%
\begin{frame}
\frametitle{Conclusion}

\textbf{Bilan}
\begin{itemize}
  \item Pendule inversé sur chariot comme support d'étude du contrôle actif d'une dynamique instable
  \item Deux stratégies de contrôle comparées :
  \begin{itemize}
    \item \textbf{PD} — intuitif, paramètres à sens physique clair (gain, amortissement), mais ne stabilise pas la position du chariot
    \item \textbf{LQR} — optimal au sens d'un critère quadratique, s'appuie sur un modèle linéarisé, contrôle simultané de $\varphi$ et $x$
  \end{itemize}
\end{itemize}

\vspace{0.4cm}

\textbf{Perspectives}
\begin{itemize}
  \item \textbf{LQG} — ajout d'un filtre de Kalman pour l'estimation des états bruités ($\dot{x}$, $\dot{\varphi}$) ; extension naturelle du LQR
  \item \textbf{MPC} (commande prédictive) — optimisation sur un horizon glissant, permet de prendre en compte explicitement certaines contraintes physiques
\end{itemize}

\end{frame}

\begin{frame}[allowframebreaks]{Références}
  \printbibliography[heading=none]
\end{frame}

%%%%%%%%%%%%%%%%%%%%%%%%%%%%%%%%%%%%%%%%%%%%%%%%
% SLIDES DE BACKUP
%%%%%%%%%%%%%%%%%%%%%%%%%%%%%%%%%%%%%%%%%%%%%%%%

\appendix

\begin{frame}
\frametitle{Annexe — Matériel}
\framesubtitle{Récupération d'une imprimante 3D Alfawise U20}

\begin{center}
    
\end{center}

\end{frame}

%%%%%%%%%%%%%%%%%%%%%%%%%%%%%%%%%%%%%%%%%%%%%%%%

\begin{frame}
\frametitle{Annexe — Identification du modèle}
\framesubtitle{Réponse libre — masse 100\,g}

\begin{center}
    
\end{center}

\vspace{0.2cm}
{\small
Avec une masse plus importante, la friction est négligeable devant l'inertie :
le modèle linéarisé reproduit fidèlement la réponse libre expérimentale.
}

\end{frame}

%%%%%%%%%%%%%%%%%%%%%%%%%%%%%%%%%%%%%%%%%%%%%%%%

\begin{frame}
\frametitle{Annexe — Équivalence LQR / PD}
\framesubtitle{Le LQR comme double correcteur PD}

\begin{center}
\begin{tikzpicture}[>=Stealth,
    block/.style={draw, rectangle, rounded corners=3pt, fill=blue!8,
                  minimum height=0.85cm, minimum width=1.7cm,
                  align=center, font=\small},
    plant/.style={draw, rectangle, rounded corners=3pt, fill=blue!8,
                  minimum height=2.1cm, minimum width=1.7cm,
                  align=center, font=\small},
    sum/.style={draw, circle, minimum size=0.55cm, inner sep=0pt},
  ]

  \node[sum]   (sum_phi) at (0,   0.85) {};
  \node[sum]   (sum_x)   at (0,  -0.85) {};
  \node[block] (pd_phi)  at (2.3,  0.85) {PD$_\varphi$};
  \node[block] (pd_x)    at (2.3, -0.85) {PD$_x$};
  \node[sum]   (sum_u)   at (4.0,  0)    {};
  \node[plant] (plant)   at (6.0,  0)    {Pendule\\inversé};

  % +/- labels
  \node[font=\scriptsize, above left=-5pt and 2pt of sum_phi] {$+$};
  \node[font=\scriptsize, above left=2pt and -5pt of sum_phi] {$-$};
  \node[font=\scriptsize, above left=-5pt and 2pt of sum_x] {$+$};
  \node[font=\scriptsize, below left=2pt and -5pt of sum_x]   {$-$};
  \node[font=\scriptsize, above left=2pt and -5pt of sum_u]   {$+$};
  \node[font=\scriptsize, below left=2pt and -5pt of sum_u]   {$+$};

  % References
  \draw[->] (-1.5,  0.85) node[above right,font=\small] {$\theta_\mathrm{ref}$} -- (sum_phi.west);
  \draw[->] (-1.5, -0.85) node[above right,font=\small] {$x_\mathrm{ref}$} -- (sum_x.west);

  % Forward path
  \draw[->] (sum_phi.east) -- node[above,font=\scriptsize] {$\varepsilon_\varphi$} (pd_phi.west);
  \draw[->] (sum_x.east)   -- node[above,font=\scriptsize] {$\varepsilon_x$}       (pd_x.west);
  \draw[->] (pd_phi.east)  -| (sum_u.north);
  \draw[->] (pd_x.east)    -| (sum_u.south);
  \draw[->] (sum_u.east)   -- node[above,font=\scriptsize] {$u = \ddot{x}$} (plant.west);

  % Plant outputs
  \coordinate (phi_out) at ($(plant.east)+(0,  0.45)$);
  \coordinate (x_out)   at ($(plant.east)+(0, -0.45)$);
  \draw[->] (phi_out) -- ++(0.75, 0) node[right,font=\small] {$\theta$};
  \draw[->] (x_out)   -- ++(0.75, 0) node[right,font=\small] {$x$};

  % Feedback paths (routed below the diagram)
  \draw[->] ($(phi_out)+(0.35,0)$)node{$\bullet$} -- ++(0, 1.2) -| (sum_phi.north);
  \draw[->] ($(x_out)+(0.35,0)$)node{$\bullet$}   -- ++(0,-1.2) -| (sum_x.south);
  % \draw[->] ($(x_out)  +(0.35,0)$) -- ++(0,-2.3) -- ($(sum_x.south)  +(0,-2.3)$) -- (sum_x.south);
\end{tikzpicture}
\end{center}

\vspace{1em}
    \[u = \underbrace{-k_\varphi\,\varepsilon_\varphi - k_{\dot\varphi}\,\dot\varphi}_{\text{PD}_\varphi} \underbrace{- k_x\,\varepsilon_x - k_{\dot x}\,\dot x}_{\text{PD}_x},
\quad\quad
    \text{LQR}: \quad \mathbf{K} = \begin{bmatrix} k_x & k_{\dot x} & k_\varphi & k_{\dot\varphi} \end{bmatrix} \]

\end{frame}

%%%%%%%%%%%%%%%%%%%%%%%%%%%%%%%%%%%%%%%%%%%%%%%%

\begin{frame}[fragile]
\frametitle{Annexe — Code}
\framesubtitle{Identification des paramètres du modèle (\texttt{tools/fit.py})}

Minimisation des moindres carrés entre simulation et mesure :

\begin{lstlisting}[style=python]
def simulate_free(t_eval, theta0, omega0, l, c, m):
    D = (1/12)*m*(2*l)**2 + m*l**2   # = 4/3 * m * l^2
    def ode(t, y):
        theta, omega = y
        return [omega, (-c*omega - m*G*l*np.sin(theta)) / D]
    sol = solve_ivp(ode, (t_eval[0], t_eval[-1]), [theta0, omega0], t_eval=t_eval)
    return sol.y[0]

def cost(params, t, theta_meas, m):
    l, c = params
    theta_sim = simulate_free(t, theta_meas[0], 0.0, l, c, m)
    return float(np.mean((theta_sim - theta_meas)**2))

result = minimize(cost, [l_init, c_init], args=(t, theta, m), method="Nelder-Mead")
l_fit, c_fit = result.x
\end{lstlisting}

\vspace{0.1cm}
{\small Algorithme de Nelder-Mead sur les paramètres $(l, c)$, masse $m$ fixée.}

\end{frame}

%%%%%%%%%%%%%%%%%%%%%%%%%%%%%%%%%%%%%%%%%%%%%%%%

\begin{frame}[fragile]
\frametitle{Annexe — Code}
\framesubtitle{Simulation du système (\texttt{model/inverted\_pendulum.py})}

\begin{columns}[T]
  \begin{column}{0.48\textwidth}
    Dynamique non-linéaire :
\begin{lstlisting}[style=python]
def dynamics(self, state, u):
    x, v, theta, omega = state
    D = p.I + p.m*p.l**2
    domega = (- p.c*omega
         - p.m*p.g*p.l*np.sin(theta)
         - p.m*p.l*u*np.cos(theta)) / D
    return np.array([v, u, omega, domega])
\end{lstlisting}
    Intégration Euler, $dt = 1\,\text{ms}$ :
\begin{lstlisting}[style=python]
for k in range(N):
    u = controller(t[k], x)
    dx = plant.dynamics(x, u)
    x  = x + dx * dt
    history[k] = x
\end{lstlisting}
  \end{column}
  \begin{column}{0.48\textwidth}
    Synthèse LQR :
\begin{lstlisting}[style=python]
Q = np.diag([q_x, 0, q_phi, 0])
R = np.array([[1]])
K, P, E = control.lqr(A, B, Q, R)
\end{lstlisting}
    \vspace{0.2cm}
    Contrôleur LQR :
\begin{lstlisting}[style=python]
def __call__(self, t, state):
    phi_state = state.copy()
    phi_state[2] = state[2] - np.pi
    u = float((-self.K @ phi_state).item())
    return u
\end{lstlisting}
  \end{column}
\end{columns}

\end{frame}

%%%%%%%%%%%%%%%%%%%%%%%%%%%%%%%%%%%%%%%%%%%%%%%%

\begin{frame}[fragile]
\frametitle{Annexe — Code}
\framesubtitle{Contrôleur embarqué — Teensy 4.1 (\texttt{teensy/src/main.cpp})}

Boucle de contrôle à 1\,kHz via \texttt{IntervalTimer} :

\begin{lstlisting}[style=cpp]
// Convert to SI units
float phi_rad     = (pend_deg   - theta_ref_deg) * (PI / 180.0f);
float phi_dot_rad =  pend_vel_deg_s              * (PI / 180.0f);
float x_m         = (cart_mm    - x_ref_mm)      / 1000.0f;
float x_dot_m     =  cart_vel_mm_s               / 1000.0f;

// Controller output [m/s^2]
switch (ctrl_mode) {
    case MODE_PD:
        accel_m_s2 = -Kp * phi_rad - Kd * phi_dot_rad;  break;
    case MODE_LQR:
        accel_m_s2 = -(K[0]*x_m + K[1]*x_dot_m + K[2]*phi_rad + K[3]*phi_dot_rad);  break;
}

// Soft braking: block acceleration toward cart limits (+/-160 mm)
if (cart_mm >  CART_SOFT_MM && accel_cmd > 0.0f) accel_cmd = 0.0f;
if (cart_mm < -CART_SOFT_MM && accel_cmd < 0.0f) accel_cmd = 0.0f;

cart_vel_mm_s += accel_cmd * DT;   // integrate acceleration -> velocity
\end{lstlisting}

\end{frame}

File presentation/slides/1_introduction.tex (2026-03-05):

\section{Introduction}

\begin{frame}
\frametitle{Introduction}
\framesubtitle{Applications}

\begin{figure}
    \begin{minipage}[t]{0.32\linewidth}
        \centering
        \\[2pt]
        \parbox{\linewidth}{\centering\scriptsize Lanceur Réutilisable~\cite{spacex}}
    \end{minipage}\hfill
    \begin{minipage}[t]{0.32\linewidth}
        \centering
        \\[2pt]
        \parbox{\linewidth}{\centering\scriptsize Segway~\cite{segway}}
    \end{minipage}\hfill
    \begin{minipage}[t]{0.32\linewidth}
        \centering
        \\[2pt]
        \parbox{\linewidth}{\centering\scriptsize Robot auto-équilibré~\cite{bostondynamics}}
    \end{minipage}
\end{figure}

\end{frame}

%%%%%%%%%%%%%%%%%%%%%%%%%%%%%%%%%%%%%%%%%%%%%%%%

\begin{frame}
\frametitle{Introduction}
\framesubtitle{Le Pendule Inversé}

\begin{figure}
    \begin{minipage}[t]{0.32\linewidth}
        \centering
        \\[2pt]
        \parbox{\linewidth}{\centering\scriptsize Pendule inversé rotatif~\cite{quanser_rotary}}
    \end{minipage}\hfill
    \begin{minipage}[t]{0.64\linewidth}
        \centering
        \\[2pt]
        \parbox{\linewidth}{\centering\scriptsize Pendule inversé sur chariot~\cite{acrome_linear}}
    \end{minipage}
\end{figure}

\end{frame}

%%%%%%%%%%%%%%%%%%%%%%%%%%%%%%%%%%%%%%%%%%%%%%%%

\begin{frame}
\frametitle{Introduction}
\framesubtitle{Problématique}

\vfill
\begin{center}
\begin{tcolorbox}[
    width=0.9\linewidth,
    colback=blue!5,
    colframe=blue!50!black,
    arc=4pt,
    boxrule=1pt,
    fontupper=\large
]
Comment la dynamique d'un système mécanique au voisinage d'un équilibre instable peut-elle être modifiée afin d'assurer sa stabilité au cours du temps, comme dans le cas des lanceurs réutilisables lors de leur retour vertical~?
\end{tcolorbox}
\end{center}
\vfill

\end{frame}

%%%%%%%%%%%%%%%%%%%%%%%%%%%%%%%%%%%%%%%%%%%%%%%%

\begin{frame}
\frametitle{Plan de l'exposé} 
\framesubtitle{Démarche}

\tableofcontents 

\end{frame}

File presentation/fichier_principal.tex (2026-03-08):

% On découpe ce document complexe en plusieurs sous-fichiers séparés.
% Cela permettra notamment de réarranger les transparents facilement 
% lors de l'élaboration du document.

% La définition de la classe beamer avec tous les styles afférents

\documentclass[9pt]{beamer}

\input{preambule/special_beamer.tex}

% Les autres packages utiles  notamment pour le français, les accents ou Python
\input{preambule/autres_packages.tex}
% Les macros et raccourcis personnels
\input{preambule/macros.tex}

% On définit le titre et l'auteur du document

% L'argument optionnel (entre crochets) donne le titre qui sera mis sur chaque slide
\title[TIPE Pendule Inversé]{Stabilisation active de systèmes en équilibre instable:\newline du pendule aux lanceurs réutilisables}
\author{Thibaut \textsc{Dehaeze (26351)}} % Votre nom
% L'épreuve (car on n'a pas le droit de signaler sa provenance à un concours) (là encore, l'argument optionnel apparaît sur chaque slide)
\institute[TIPE]{Épreuve de TIPE}
\date{Session 2026}

% On démarre le document proprement dit
\begin{document}

\begin{frame}
\titlepage 
\end{frame}

% La première grande partie: introduction du sujet
\input{slides/1_introduction.tex}

% La 2e partie: Etude de la dynamique
\input{slides/2_dynamique.tex}

% La 3e partie: Controle par PID
\input{slides/3_control_pid.tex}

% La 4e partie: Controle par LQR
\input{slides/4_control_lqr.tex}

% Conclusion
\input{slides/5_conclusion.tex}

\end{document}

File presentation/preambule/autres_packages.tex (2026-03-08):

\usepackage{url}            % Pour citer les adresses web
\usepackage[T1]{fontenc}    % Encodage des accents
\usepackage[utf8]{inputenc} % Lui aussi
\usepackage[french]{babel}  % Pour la traduction française
\usepackage{numprint}       % Histoire que les chiffres soient bien

\usepackage{amsmath}        % La base pour les maths
\usepackage{mathrsfs}       % Quelques symboles supplémentaires
\usepackage{amssymb}        % encore des symboles.
\usepackage{amsfonts}       % Des fontes, eg pour \mathbb.

\usepackage{cancel}

\usepackage{caption}
\captionsetup[figure]{
  labelformat=simple,       % affiche juste le numéro
  labelsep=period,          % séparateur point
  name=Fig.,                % remplace "Figure" par "Fig."
  font=scriptsize,          % texte très petit (ou "tiny" encore plus petit)
  skip=2pt                  % espace minimal entre figure et caption
}

\usepackage[backend=biber, style=numeric, sorting=none]{biblatex}
\addbibresource{references.bib}

%\usepackage[svgnames]{xcolor} % De la couleur

%%% Si jamais vous voulez changer de police: décommentez les trois 
%\usepackage{tgpagella}
%\usepackage{tgadventor}
%\usepackage{inconsolata}

\usepackage{graphicx} % inclusion des graphiques
\usepackage{wrapfig}  % Dessins dans le texte.

\usepackage{appendixnumberbeamer}
\usepackage{listings}
\lstset{
  basicstyle=\ttfamily\tiny,
  keywordstyle=\color{blue!70!black}\bfseries,
  commentstyle=\color{gray}\itshape,
  stringstyle=\color{orange!80!black},
  showstringspaces=false,
  breaklines=true,
  frame=single,
  framerule=0.4pt,
  backgroundcolor=\color{gray!6},
  xleftmargin=4pt, xrightmargin=4pt,
  aboveskip=4pt, belowskip=4pt,
}
\lstdefinestyle{python}{language=Python}
\lstdefinestyle{cpp}{language=C++}

\usepackage{tikz}     % Un package pour les dessins (utilisé pour l'environnement {code})
\usetikzlibrary{calc, patterns, arrows.meta, positioning}
\usepackage[framemethod=TikZ]{mdframed}
\usepackage{tcolorbox}

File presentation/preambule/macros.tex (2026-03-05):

% Ce fichier contient toutes les macros que vous pouvez avoir envie de définir 
% si vous les utilisez plusieurs fois dans le document.

\PassOptionsToPackage{svgnames}{color}

% Un environnement pour bien présenter le code informatique
\newenvironment{code}{%
\begin{mdframed}[linecolor=green,innerrightmargin=30pt,innerleftmargin=30pt,
backgroundcolor=black!5,
skipabove=10pt,skipbelow=10pt,roundcorner=5pt,
splitbottomskip=6pt,splittopskip=12pt]
}{%
\end{mdframed}
}

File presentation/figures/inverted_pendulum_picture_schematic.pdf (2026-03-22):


Moteur

Chariot Encodeur

Courroie

Electronique

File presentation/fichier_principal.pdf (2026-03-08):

Introduction
Étude de la dynamique du Pendule Inversé Stabilisation de la dynamique par contrôle PD Stabilisation de la dynamique par contrôle LQ Conclusion

# Stabilisation active de systèmes en équilibre instable: du pendule aux lanceurs réutilisables

# Thibaut Dehaeze (26351)

### Épreuve de TIPE

# Session 2026

Thibaut Dehaeze (26351) | TIPE Pendule Inversé | 1 / 19

# Introduction

## Applications


Conclusion

Lanceur Réutilisable [1] | Segway [2] | Robot auto-équilibré [3]

# Introduction

## Le Pendule Inversé


Conclusion

Pendule inversé rotatif [4] | Pendule inversé sur chariot [5]

Conclusion

# Introduction

## Problématique

# Comment la dynamique d’un système mécanique au voi-sinage d’un équilibre instable peut-elle être modifiée afin d’assurer sa stabilité au cours du temps, comme dans le cas des lanceurs réutilisables lors de leur retour vertical ?

Conclusion

# Plan de l’exposé

## Démarche

1 | Introduction
2 | Étude de la dynamique du Pendule Inversé
3 | Stabilisation de la dynamique par contrôle PD
4 | Stabilisation de la dynamique par contrôle LQ
5 | Conclusion

Conclusion

# Étude de la dynamique

## Présentation du système


Conclusion

# Étude de la dynamique

## Présentation du système


Conclusion

# Étude de la dynamique

## Modèle et Équations de la dynamique


u = ¨x

# Équation du mouvement :

1
3

# ml² ¨θ + c

# ˙θ + mgl sin θ + ml cos θ · u

| | {z | }
| non linéaire

= 0

Conclusion

# Étude de la dynamique

## Modèle et Équations de la dynamique


u = ¨x

# Équation du mouvement :

1
3

# ml² ¨θ + c

# ˙θ + mgl sin θ + ml cos θ · u

| | {z | }
| non linéaire

= 0

# Linéarisation pour étude de la dynamique et contrôle

Conclusion

# Étude de la dynamique

## Linéarisations et Réponses du système

# Position basse (θ ≈ 0)

1
3

# ml² ¨θ + c

# ˙θ + mgl θ = −mlu

# ⇒ Oscillations amorties


# Étude de la dynamique

## Linéarisations et Réponses du système


Conclusion

# Position basse (θ ≈ 0)

1
3

# ml² ¨θ + c

# ˙θ + mgl θ = −mlu

# ⇒ Oscillations amorties

# Position haute (φ = θ − π ≈ 0)

1
3

# ml² φ¨ + c φ˙ − mgl φ = mlu

# ⇒ Divergence exponentielle

Conclusion

# Étude de la dynamique

## Comparaison modèle / expérience

## Mesure de la réponse expérimentale


Conclusion

# Étude de la dynamique

## Comparaison modèle / expérience


Conclusion

# Contrôle PD

## Schéma block du contrôle du pendule inversé

# u(t) = kp · εθ(t)

| {z }

### Proportionnel

+ kd ·

# dεθ(t)

dt
| | {z | }
| Dérivé

# Contrôle PD

## Contrôleur Proportionnel


Conclusion

# Avec u = −kp φ, l’équation linéarisée devient :

1
3

# ml² φ¨ + c φ˙ + (ml kp − mgl) φ = 0

# Stable si ∆ = c

2 − 4
1

# 3ml² - (ml kp − mgl) > 0, donc si kp > kp,c, avec

# kp,c = g +

3c

2

# 4m²l

3 ≈ 9.8

Conclusion

# Contrôle PD

## Contrôleur Dérivatif

# Avec u = −kp φ − kd φ˙, l’équation linéarisée devient :

1
3

# ml² φ¨ + (c + ml kd) ˙φ + (ml kp − mgl) φ = 0

# Amortissement critique :

### kd,c =

1
ml

2

r
1
3

# ml² (ml kp − mgl) − c

!
≈ 1.2


Conclusion

# Contrôle PD

## Résultats expérimentaux


### Résultats expérimentaux — kp = 12, kd = 1

Conclusion

# Contrôle PD

## Résultats expérimentaux


### Résultats expérimentaux — kp = 12, kd = 1

Conclusion

# Contrôle PD

## Résultats expérimentaux

Résultats expérimentaux — kp = 12, kd = 1 | Même comportement en simulation :

# ϕ est correctement stabilisé, mais le

chariot n’est pas stable.


### Résultats de simulation — kp = 12, kd = 1

# Pour contrôler à la fois ϕ et x, le

contrôleur PD n’est pas adapté.

Conclusion

# Contrôle LQ

## Modèle d’état — Commande par retour d’état

# Modèle par représentation d’états :

X =

x
x˙
φ
φ˙

, | X˙ = AX + Bu, | A =

0 | 1 | 0 | 0
0 | 0 | 0 | 0
0 | 0 | 0 | 1
0 | 0 | mgl
| | D | − c
| | | D

, B =

0
1
0
ml
D

# Commande par retour d’état :

# u(t) = K

# Xref − X(t)

, K =
kx | kx˙ | kφ | kφ˙

Conclusion

# Contrôle LQ

## Choix de la matrice de retour d’état

# Minimisation d’un critère quadratique :

J =

Z ∞

0

X

# ⊤Q X + u

⊤R u
dt

# Q ⪰ 0 pondère les états : Q = diag(qx, qx˙ , qφ, qφ˙)

# R > 0 pondère l’effort de commande

# K est obtenu par résolution de l’équation algébrique de Riccati :

A

# ⊤P + P A − P BR⁻¹B

# ⊤P + Q = 0 =⇒ K = R

−1B

⊤P

# Exemple qx = 100, qφ = 1, R = 1 =⇒ K =

−10.0 | −8.7 | 46.9 | 9.8

# Contrôle LQ

## Simulation


Conclusion

Pondération forte sur φ : qx = 1, qφ = 100 | Pondération forte sur x : qx = 100, qφ = 1

Conclusion

# Contrôle LQ

## Résultats Expérimentaux


### K = [−31.6 − 23.1 92.8 18.3], stabilité observée de ±1 deg, ±4 mm

Conclusion

# Conclusion

# Bilan

# Pendule inversé sur chariot comme support d’étude du contrôle actif d’une dynamique instable Deux stratégies de contrôle comparées :

PD — intuitif, paramètres à sens physique clair (gain, amortissement),

## mais ne stabilise pas la position du chariot LQR — optimal au sens d’un critère quadratique, s’appuie sur un modèle linéarisé, contrôle simultané de φ et x

# Perspectives

# LQG — ajout d’un filtre de Kalman pour l’estimation des états bruités (x˙, φ˙) ; extension naturelle du LQR

MPC (commande prédictive) — optimisation sur un horizon glissant,

# permet de prendre en compte explicitement certaines contraintes physiques

Conclusion

# Références I

# [1] Programme de développement de lanceurs réutilisables – SpaceX. url :

## https://fr.wikipedia.org/wiki/Programme_de_d%C3%

A9veloppement_de_lanceurs_r%C3%A9utilisables_de_SpaceX (https://fr.wikipedia.org/wiki/Programme_de_d%C3%A9veloppement_de_lanceurs_r%C3%A9utilisables_de_SpaceX) (visité le 04/03/2026).

## [2] Gyropode. url : https://fr.wikipedia.org/wiki/Gyropode (visité le

04/03/2026).

# [3] Boston Dynamics – History. url :

https://bostondynamics.com/about/history/ (visité le 04/03/2026).

# [4] Quanser – Inverted Rotary Pendulum. url :

## https://edu4industry.com/en/produkt/quanser-inverted-rotary-

pendulum/ (https://edu4industry.com/en/produkt/quanser-inverted-rotary-pendulum/) (visité le 04/03/2026).

# [5] Acrome – Linear Inverted Pendulum. url :

## https://acrome.net/product/linear-inverted-pendulum (visité le

04/03/2026).

# Annexe — Matériel

## Récupération d’une imprimante 3D Alfawise U20


# Annexe — Identification du modèle

## Réponse libre — masse 100 g


## Avec une masse plus importante, la friction est négligeable devant l’inertie : le

modèle linéarisé reproduit fidèlement la réponse libre expérimentale.

# Annexe — Code

## Identification des paramètres du modèle (tools/fit.py)

# Minimisation des moindres carrés entre simulation et mesure :

def simulate_free ( t_eval , theta0 , omega0 , l , c , m) :
D = (1/12) *m *(2* l ) **2 + m*l **2 # = 4/3 * m * l^2
def ode (t , y ):
theta , omega = y
return [ omega , (- c* omega - m* G*l* np . sin ( theta )) / D]
sol = solve_ivp ( ode , ( t_eval [0] , t_eval [ -1]) , [ theta0 , omega0 ] , t_eval = t_eval ) return sol .y [0]

def cost ( params , t , theta_meas , m):
l , c = params
theta_sim = simulate_free (t , theta_meas [0] , 0.0 , l , c , m)
return float ( np . mean (( theta_sim - theta_meas ) **2) )

result = minimize ( cost , [ l_init , c_init ] , args =(t , theta , m ) , method =" Nelder - Mead ") l_fit , c_fit = result .x

Algorithme de Nelder-Mead sur les paramètres (l, c), masse m fixée.

# Annexe — Code

## Simulation du système (model/inverted_pendulum.py)

# Dynamique non-linéaire :

def dynamics ( self , state , u ): x , v , theta , omega = state
D = p .I + p. m*p. l **2
domega = (- p .c* omega
- p.m *p.g *p.l * np . sin ( theta )
- p.m *p.l *u* np . cos ( theta ) ) / D return np . array ([v , u , omega , domega ])

# Intégration Euler, dt = 1 ms :

for k in range ( N):
u = controller (t[ k], x)
dx = plant . dynamics (x , u ) x = x + dx * dt
history [k] = x

# Synthèse LQR :

Q = np . diag ([ q_x , 0, q_phi , 0]) R = np . array ([[1]])
K , P , E = control . lqr (A , B , Q , R)

# Contrôleur LQR :

def __call__ ( self , t , state ) :
phi_state = state . copy ()
phi_state [2] = state [2] - np . pi
u = float (( - self .K @ phi_state ). item () ) return u

# Annexe — Code

## Contrôleur embarqué — Teensy 4.1 (teensy/src/main.cpp)

# Boucle de contrôle à 1 kHz via IntervalTimer :

// Convert to SI units
float phi_rad | = ( pend_deg | - theta_ref_deg ) * ( PI / 180.0 f);
float phi_dot_rad = | pend_vel_deg_s | * ( PI / 180.0 f );
float x_m | = ( cart_mm | - x_ref_mm ) | / 1000.0 f ;
float x_dot_m | = | cart_vel_mm_s | / 1000.0 f ;

// Controller output [m/s^2]
switch ( ctrl_mode ) {
case MODE_PD :
accel_m_s2 = -Kp * phi_rad - Kd * phi_dot_rad ; break ;
case MODE_LQR :
accel_m_s2 = -( K [0]* x_m + K [1]* x_dot_m + K [2]* phi_rad + K [3]* phi_dot_rad ) ; break ; }

// Soft braking : block acceleration toward cart limits (+/ -160 mm)
if ( cart_mm > CART_SOFT_MM && accel_cmd > 0.0 f) accel_cmd = 0.0 f ;
if ( cart_mm < - CART_SOFT_MM && accel_cmd < 0.0 f) accel_cmd = 0.0 f ;

cart_vel_mm_s += accel_cmd * DT ; // integrate acceleration -> velocity

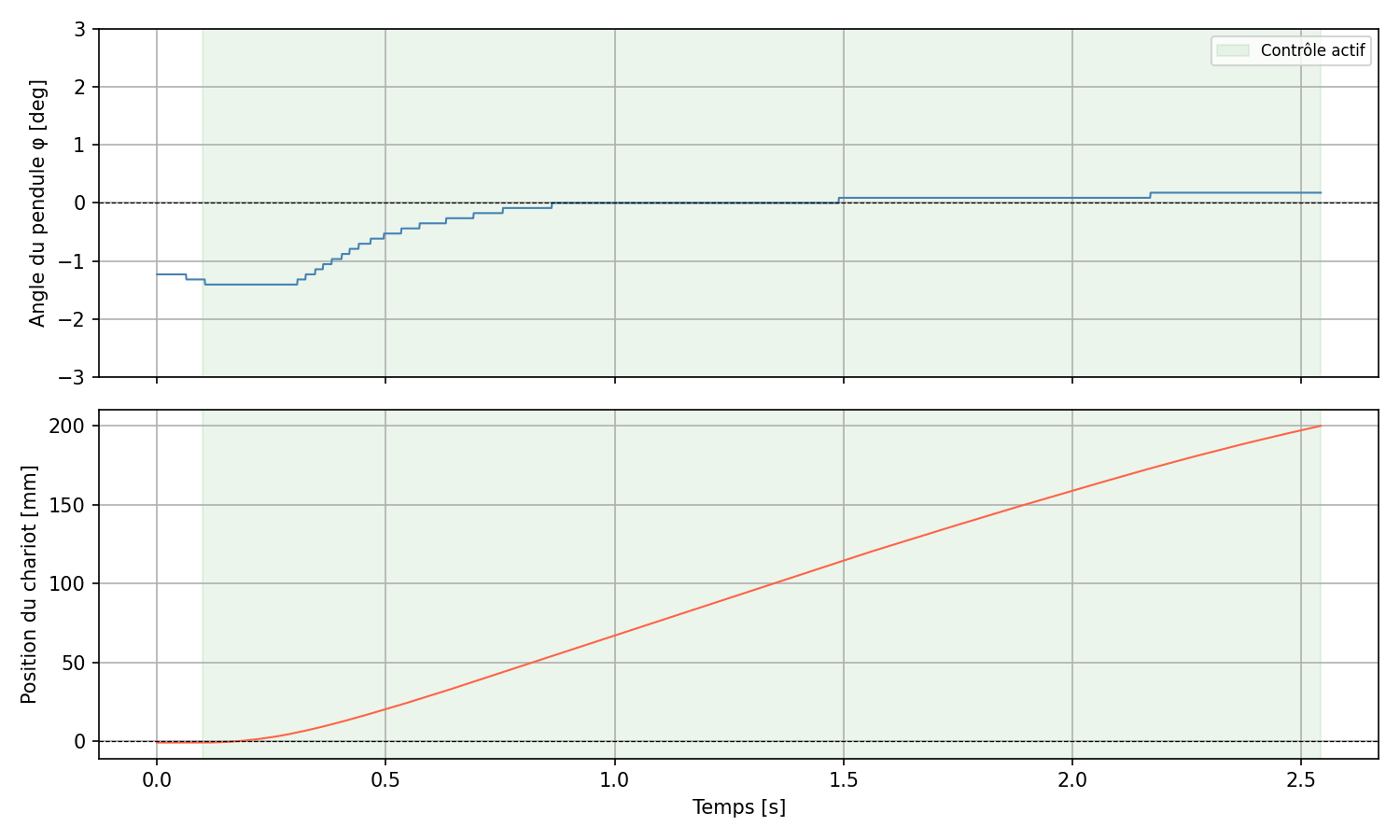
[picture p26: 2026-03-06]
presentation/figures/kp_12_kd_1_stable_bis.png

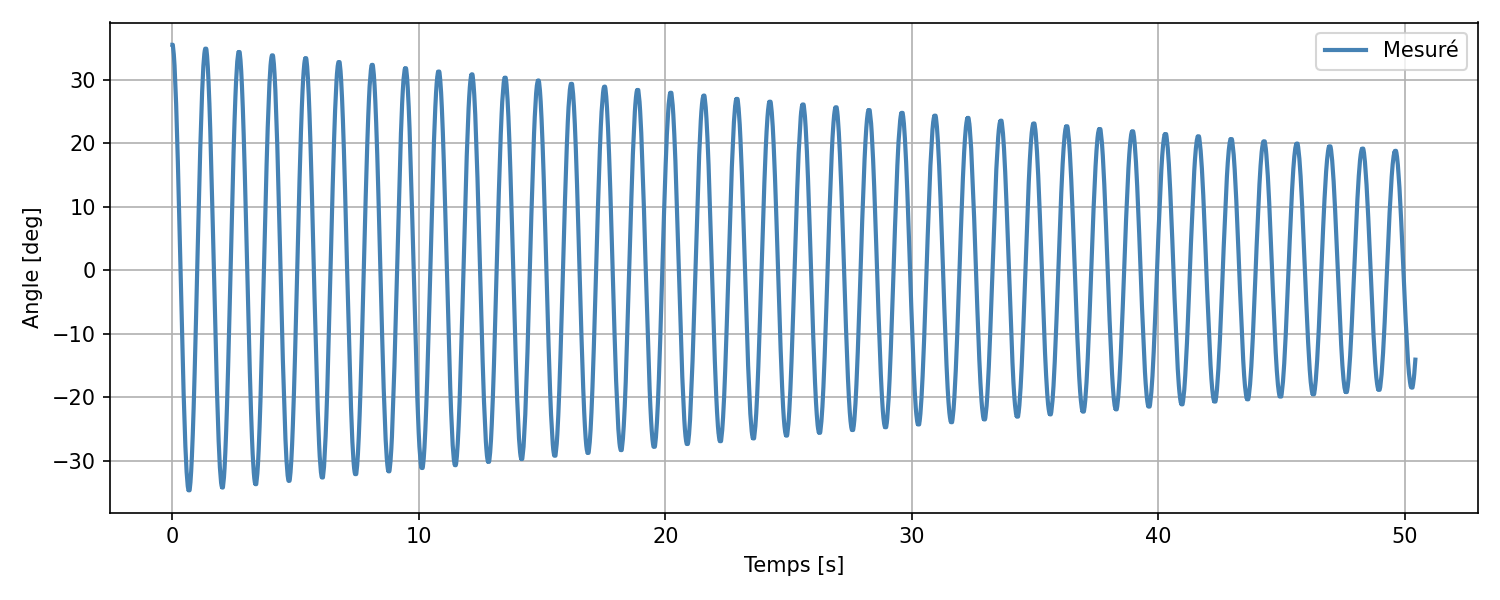
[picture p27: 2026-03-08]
presentation/figures/free_response_100g_data.png

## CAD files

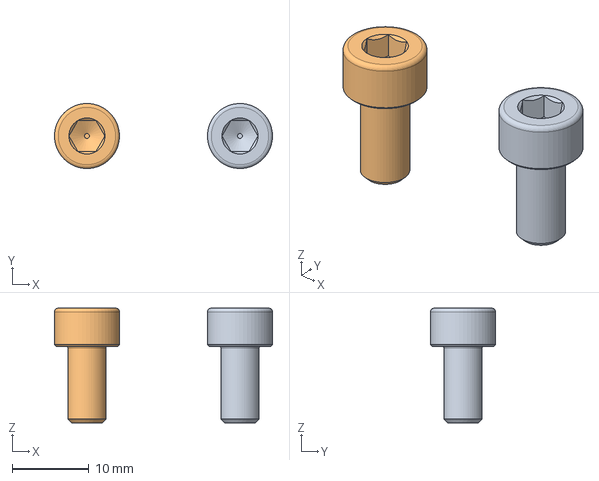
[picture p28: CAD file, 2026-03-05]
mechanical-setup/inverted_pendulum.FCStd
28.5 x 8.50 x 15.0 mm
M5x10-Screw
M5x10-Screw001

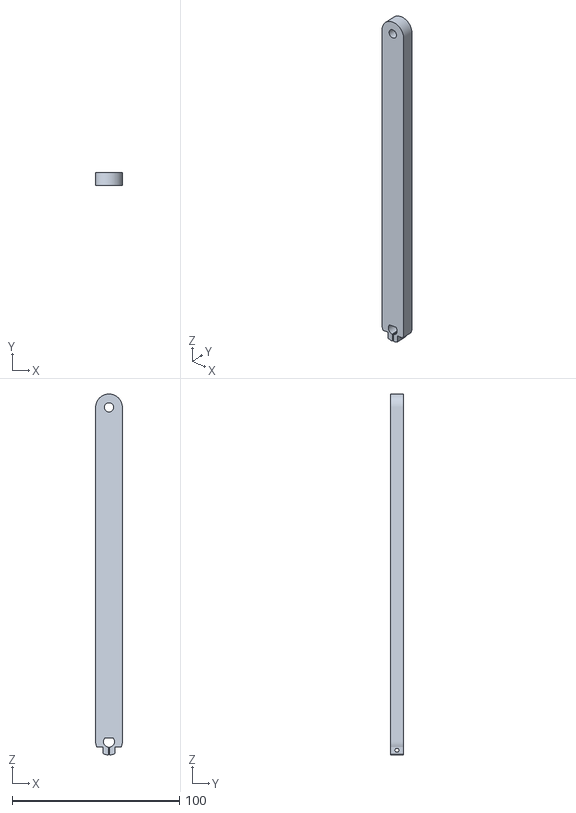
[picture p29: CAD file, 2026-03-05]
mechanical-setup/stl/pendulum_200mm.stl
16.0 x 8.00 x 216.0

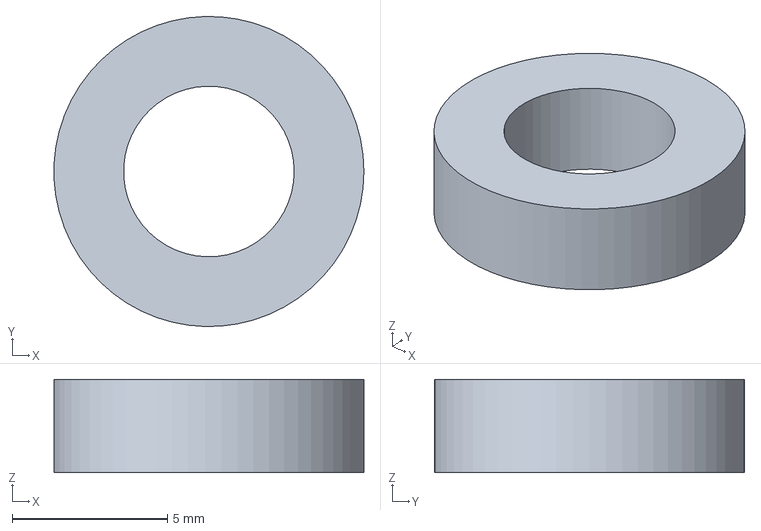
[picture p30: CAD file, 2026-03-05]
mechanical-setup/3mm_space.FCStd
9.99 x 10.00 x 3.00 mm

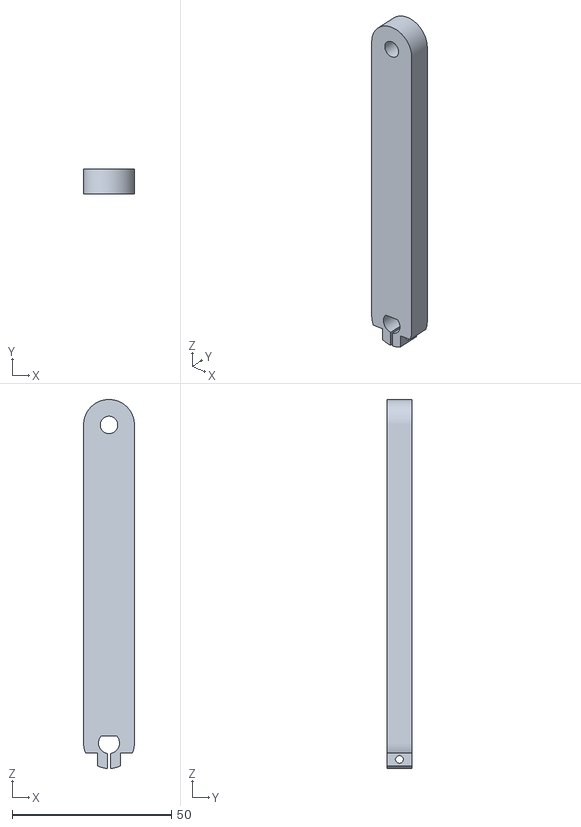
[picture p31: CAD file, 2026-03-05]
mechanical-setup/stl/pendulum_100mm.stl
16.0 x 8.00 x 116.0

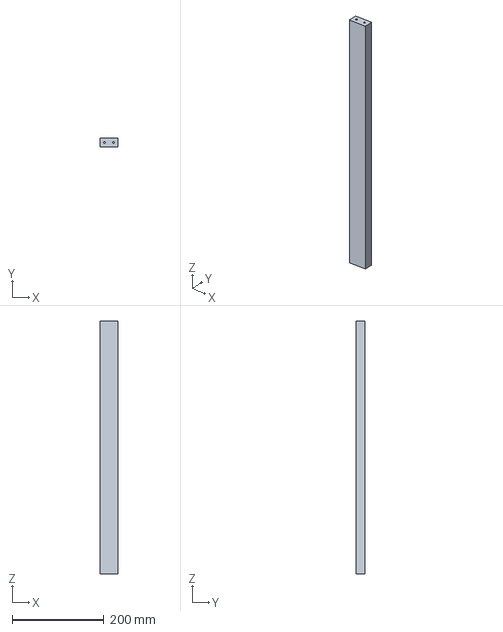
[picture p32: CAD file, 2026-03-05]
mechanical-setup/vslot.FCStd
40.0 x 20.0 x 550.0 mm

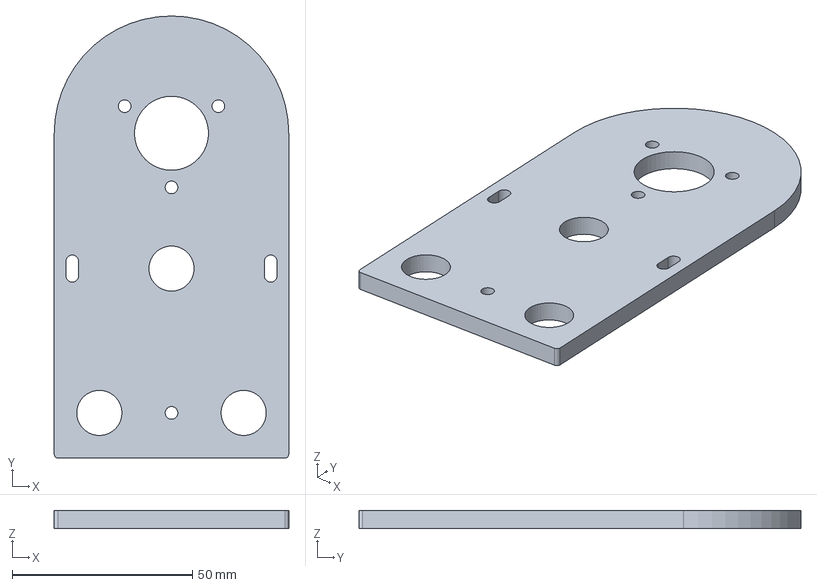
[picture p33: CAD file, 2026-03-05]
mechanical-setup/encoder_support.FCStd
65.0 x 122.5 x 5.00 mm

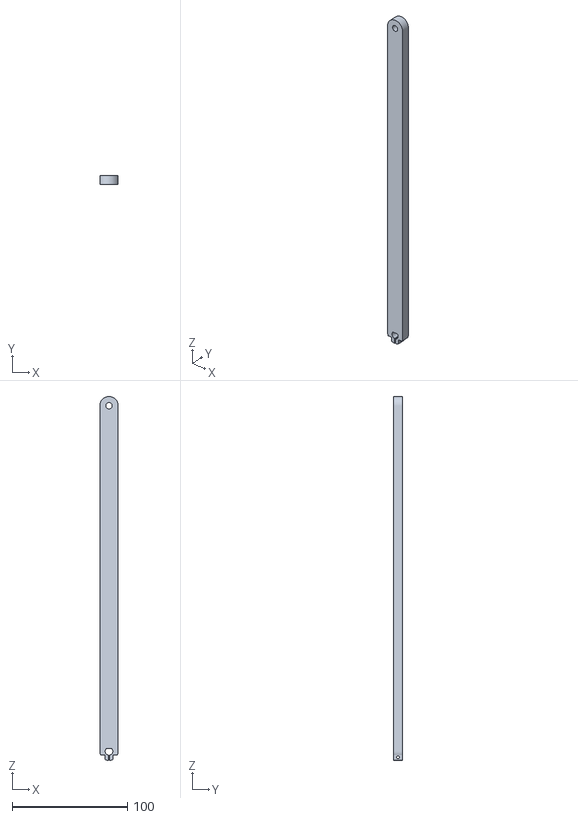
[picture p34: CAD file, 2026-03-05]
mechanical-setup/stl/pendulum_300mm.stl
16.0 x 8.00 x 316.0

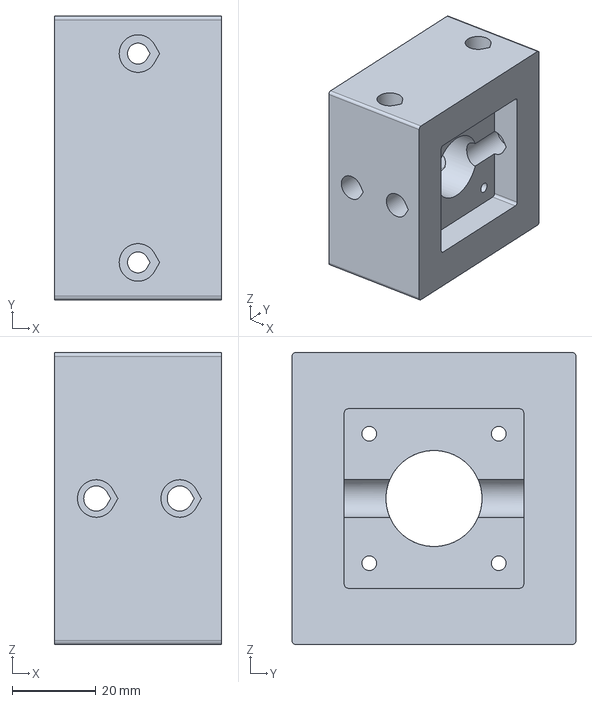
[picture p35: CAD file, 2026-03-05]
mechanical-setup/motor_support.FCStd
40.0 x 68.0 x 70.0 mm

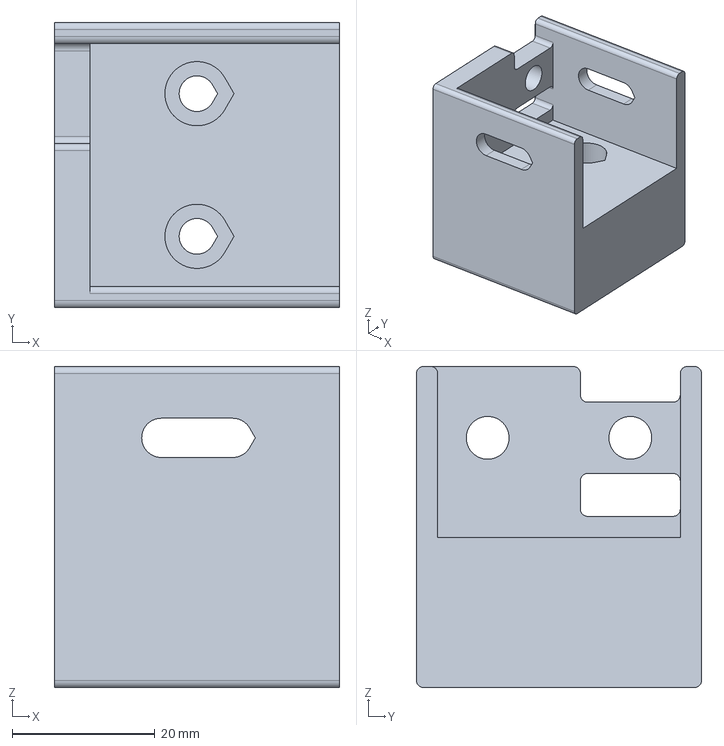
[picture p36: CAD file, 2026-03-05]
mechanical-setup/support_courroie.FCStd
40.0 x 40.0 x 45.0 mm

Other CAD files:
mechanical-setup/stl/3mm_spacer.stl
mechanical-setup/pendulum_small.FCStd
mechanical-setup/stl/encoder_support.stl
mechanical-setup/stl/motor_support.stl
mechanical-setup/stl/support_courroie.stl

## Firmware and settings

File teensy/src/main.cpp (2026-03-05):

#include <Arduino.h>
#include <IntervalTimer.h>
#include <Encoder.h>

/* =========================================================
   ===================== CONSTANTS  ========================
   ========================================================= */

// ---- Stepper pins ----
const uint8_t STEP_PIN = 10;
const uint8_t DIR_PIN  = 11;

// ---- Encoder ----
Encoder enc(2, 3);

// ---- Conversions ----
constexpr float ENC_STEPS_PER_REV = 4096.0f;
constexpr float DEG_PER_ENC_STEP  = 360.0f  / ENC_STEPS_PER_REV;
constexpr float RAD_PER_ENC_STEP  = 6.28318530f / ENC_STEPS_PER_REV;

// 200 steps/rev, 32 microsteps, 16-tooth pulley, 2 mm pitch
constexpr float CART_MM_PER_MICROSTEP = 5.0f / 1000.0f;   // 5 µm/microstep

// ---- Cart limits ----
constexpr float CART_HARD_MM = 200.0f;   // hard stop  (disable motor)
constexpr float CART_SOFT_MM = 160.0f;   // soft limit (block accel toward boundary)

// ---- Velocity / acceleration limits ----
constexpr float ACCEL_MAX_MM_S2 = 10000.0f;   // 10 m/s²
constexpr float VEL_MAX_MM_S    =   300.0f;   // 0.3 m/s

// ---- Angular velocity filter ----
// First-order low-pass on the finite-difference velocity estimate.
// Implements H(s) = s/(s + wc)  with wc = 2*pi*50 rad/s, Dt = 1 ms.
// alpha = exp(-2*pi*50*0.001) ≈ 0.7304
constexpr float ALPHA_VEL = 0.7304f;

// ---- Timing ----
constexpr uint32_t CONTROL_PERIOD_US = 1000;    // 1 kHz
constexpr float    DT                = 1e-3f;   // s

/* =========================================================
   ===================== STEPPER ===========================
   ========================================================= */

IntervalTimer stepTimer;
volatile bool    stepState = false;
volatile int32_t stepCount = 0;

void stepISR() {
    stepState = !stepState;
    digitalWriteFast(STEP_PIN, stepState);
    if (stepState) {
        stepCount += (digitalReadFast(DIR_PIN) ? 1 : -1);
    }
}

void setSpeedSteps(float sps) {
    if (sps <= 0.0f) {
        stepTimer.end();
        return;
    }
    float period_us = 5.0e5f / sps;   // 1e6 / (2 * sps)
    stepTimer.end();
    stepTimer.begin(stepISR, (uint32_t)period_us);
}

/* =========================================================
   ===================== SYSTEM STATE ======================
   ========================================================= */

volatile bool  motor_enabled   = false;
volatile bool  feedback_closed = false;

volatile float openloop_vel_mm_s = 0.0f;
volatile float cart_vel_mm_s     = 0.0f;   // velocity integrated in closed loop

volatile int32_t motor_zero_offset = 0;
volatile int32_t enc_zero_offset   = 0;

/* =========================================================
   ===================== CONTROLLER ========================
   ========================================================= */

enum CtrlMode : uint8_t { MODE_P = 0, MODE_PD = 1, MODE_LQR = 2 };

volatile CtrlMode ctrl_mode     = MODE_PD;
volatile float    Kp            = 0.0f;
volatile float    Kd            = 0.0f;
volatile float    K_lqr[4]      = {0.0f, 0.0f, 0.0f, 0.0f};  // [x, x_dot, phi, phi_dot]
volatile float    theta_ref_deg = 0.0f;   // pendulum angle setpoint [deg]
volatile float    x_ref_mm      = 0.0f;   // cart position setpoint  [mm]

/* =========================================================
   ===================== TELEMETRY =========================
   ========================================================= */

// Packet: header(2) t_us(4) angle_deg(4) pend_vel_deg_s(4)
//         cart_mm(4) cart_vel_mm_s(4) accel_mm_s2(4) feedback_on(1) = 27 bytes
struct __attribute__((packed)) Sample {
    uint16_t header;             // 0xAA55
    uint32_t t_us;
    float    pendulum_deg;
    float    pendulum_vel_deg_s;
    float    cart_mm;
    float    cart_vel_mm_s;
    float    accel_cmd_mm_s2;
    uint8_t  feedback_on;
};

constexpr uint16_t BUFFER_SIZE = 512;
volatile Sample   buffer[BUFFER_SIZE];
volatile uint16_t writeIdx = 0;
volatile uint16_t readIdx  = 0;

/* =========================================================
   ===================== UTILITIES =========================
   ========================================================= */

inline float getPendulumDeg() {
    return (enc.read() - enc_zero_offset) * DEG_PER_ENC_STEP;
}

inline float getCartMm() {
    return (stepCount - motor_zero_offset) * CART_MM_PER_MICROSTEP;
}

inline void motorOff() {
    setSpeedSteps(0);
    cart_vel_mm_s = 0.0f;
    motor_enabled = false;
}

/* =========================================================
   ===================== 1 kHz CONTROL LOOP ================
   ========================================================= */

IntervalTimer controlTimer;
static float prev_pend_deg   = 0.0f;
static float pend_vel_filt   = 0.0f;   // filtered angular velocity [deg/s]

void controlISR() {
    float pend_deg = getPendulumDeg();
    float cart_mm  = getCartMm();

    // Angular velocity: finite difference + first-order low-pass (fc = 50 Hz)
    float pend_vel_raw = (pend_deg - prev_pend_deg) / DT;
    pend_vel_filt = ALPHA_VEL * pend_vel_filt + (1.0f - ALPHA_VEL) * pend_vel_raw;
    float pend_vel_deg_s = pend_vel_filt;
    prev_pend_deg = pend_deg;

    // ---- Hard safety limits ----
    // Stop the cart and disengage feedback, but keep motor enabled so the
    // user (or "Go to Zero") can drive back toward centre.
    bool at_pos_limit = (cart_mm >= CART_HARD_MM);
    bool at_neg_limit = (cart_mm <= -CART_HARD_MM);
    if (at_pos_limit || at_neg_limit) {
        cart_vel_mm_s = 0.0f;
        feedback_closed = false;
    }

    float accel_cmd_mm_s2 = 0.0f;
    float vel_cmd_mm_s    = 0.0f;

    if (motor_enabled) {
        if (feedback_closed) {

            // Convert to SI units for the controller
            float phi_rad     = (pend_deg     - theta_ref_deg) * (3.14159265f / 180.0f);
            float phi_dot_rad = pend_vel_deg_s                 * (3.14159265f / 180.0f);
            float x_m         = (cart_mm      - x_ref_mm)     / 1000.0f;
            float x_dot_m     = cart_vel_mm_s                  / 1000.0f;

            // Controller output [m/s²]
            float accel_m_s2 = 0.0f;
            switch (ctrl_mode) {
                case MODE_P:
                    accel_m_s2 = -Kp * phi_rad;
                    break;
                case MODE_PD:
                    accel_m_s2 = -Kp * phi_rad - Kd * phi_dot_rad;
                    break;
                case MODE_LQR:
                    accel_m_s2 = -(K_lqr[0] * x_m     + K_lqr[1] * x_dot_m
                                 + K_lqr[2] * phi_rad  + K_lqr[3] * phi_dot_rad);
                    break;
            }

            // Convert to mm/s² and clamp
            accel_cmd_mm_s2 = accel_m_s2 * 1000.0f;
            if (accel_cmd_mm_s2 >  ACCEL_MAX_MM_S2) accel_cmd_mm_s2 =  ACCEL_MAX_MM_S2;
            if (accel_cmd_mm_s2 < -ACCEL_MAX_MM_S2) accel_cmd_mm_s2 = -ACCEL_MAX_MM_S2;

            // Soft braking: block acceleration toward the nearest soft limit
            if (cart_mm >  CART_SOFT_MM && accel_cmd_mm_s2 > 0.0f) accel_cmd_mm_s2 = 0.0f;
            if (cart_mm < -CART_SOFT_MM && accel_cmd_mm_s2 < 0.0f) accel_cmd_mm_s2 = 0.0f;

            // Integrate acceleration → velocity
            cart_vel_mm_s += accel_cmd_mm_s2 * DT;

            // Clamp velocity
            if (cart_vel_mm_s >  VEL_MAX_MM_S) cart_vel_mm_s =  VEL_MAX_MM_S;
            if (cart_vel_mm_s < -VEL_MAX_MM_S) cart_vel_mm_s = -VEL_MAX_MM_S;

            vel_cmd_mm_s = cart_vel_mm_s;

        } else {
            // Open loop: direct velocity command
            cart_vel_mm_s = openloop_vel_mm_s;
            vel_cmd_mm_s  = openloop_vel_mm_s;
        }
    }

    // ---- Hard limit: block movement further into the wall ----
    if (at_pos_limit && vel_cmd_mm_s > 0.0f) { vel_cmd_mm_s = 0.0f; cart_vel_mm_s = 0.0f; }
    if (at_neg_limit && vel_cmd_mm_s < 0.0f) { vel_cmd_mm_s = 0.0f; cart_vel_mm_s = 0.0f; }

    // ---- Velocity → stepper speed ----
    float steps_s = vel_cmd_mm_s / CART_MM_PER_MICROSTEP;
    if (steps_s >= 0.0f) {
        digitalWriteFast(DIR_PIN, HIGH);
        setSpeedSteps(steps_s);
    } else {
        digitalWriteFast(DIR_PIN, LOW);
        setSpeedSteps(-steps_s);
    }

    // ---- Ring buffer ----
    uint16_t next = (writeIdx + 1) % BUFFER_SIZE;
    if (next != readIdx) {
        Sample s = {0xAA55, micros(), pend_deg, pend_vel_deg_s,
                    cart_mm, vel_cmd_mm_s, accel_cmd_mm_s2, (uint8_t)feedback_closed};
        memcpy((void*)&buffer[writeIdx], &s, sizeof(Sample));
        writeIdx = next;
    }
}

/* =========================================================
   ===================== SERIAL CMD ========================
   ========================================================= */

void handleCommand(char *cmd) {

    // Motor
    if (!strcmp(cmd, "MOTOR ON"))  { motor_enabled = true; cart_vel_mm_s = 0.0f; return; }
    if (!strcmp(cmd, "MOTOR OFF")) { motorOff();                                  return; }

    // Feedback
    if (!strcmp(cmd, "FB ON"))  { cart_vel_mm_s = 0.0f; feedback_closed = true;  return; }
    if (!strcmp(cmd, "FB OFF")) { cart_vel_mm_s = 0.0f; feedback_closed = false; return; }

    // Zeroing
    if (!strcmp(cmd, "ZERO CART")) { motor_zero_offset = stepCount;   return; }
    if (!strcmp(cmd, "ZERO ENC"))  { enc_zero_offset   = enc.read();  return; }

    // Open-loop velocity [mm/s]
    if (!strncmp(cmd, "VEL ", 4)) { openloop_vel_mm_s = atof(cmd + 4); return; }

    // Controller mode
    if (!strcmp(cmd, "MODE P"))   { ctrl_mode = MODE_P;   return; }
    if (!strcmp(cmd, "MODE PD"))  { ctrl_mode = MODE_PD;  return; }
    if (!strcmp(cmd, "MODE LQR")) { ctrl_mode = MODE_LQR; return; }

    // PD gains
    if (!strncmp(cmd, "SET KP ", 7)) { Kp = atof(cmd + 7); return; }
    if (!strncmp(cmd, "SET KD ", 7)) { Kd = atof(cmd + 7); return; }

    // LQR gains: "SET K k0 k1 k2 k3"
    if (!strncmp(cmd, "SET K ", 6)) {
        float k0, k1, k2, k3;
        if (sscanf(cmd + 6, "%f %f %f %f", &k0, &k1, &k2, &k3) == 4) {
            K_lqr[0] = k0;  K_lqr[1] = k1;
            K_lqr[2] = k2;  K_lqr[3] = k3;
        }
        return;
    }

    // Setpoints
    if (!strncmp(cmd, "SET THETA ", 10)) { theta_ref_deg = atof(cmd + 10); return; }
    if (!strncmp(cmd, "SET X ",      6)) { x_ref_mm      = atof(cmd + 6);  return; }
}

/* =========================================================
   ===================== SETUP =============================
   ========================================================= */

void setup() {
    Serial.begin(115200);
    while (!Serial && millis() < 2000);

    pinMode(STEP_PIN, OUTPUT);
    pinMode(DIR_PIN, OUTPUT);
    digitalWriteFast(DIR_PIN, HIGH);

    controlTimer.begin(controlISR, CONTROL_PERIOD_US);
}

/* =========================================================
   ===================== LOOP ==============================
   ========================================================= */

void loop() {
    // ---- Command parsing ----
    static char    cmd[64];
    static uint8_t idx = 0;

    while (Serial.available()) {
        char c = Serial.read();
        if (c == '\n') {
            cmd[idx] = 0;
            handleCommand(cmd);
            idx = 0;
        } else if (idx < sizeof(cmd) - 1) {
            cmd[idx++] = c;
        }
    }

    // ---- Streaming ----
    while (readIdx != writeIdx &&
           Serial.availableForWrite() >= (int)sizeof(Sample)) {
        Serial.write((uint8_t*)&buffer[readIdx], sizeof(Sample));
        readIdx = (readIdx + 1) % BUFFER_SIZE;
    }
}

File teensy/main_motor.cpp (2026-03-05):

#include <Arduino.h>
#include <IntervalTimer.h>

// Pin mapping (modifie à ton goût)
const uint8_t STEP_PIN = 10;
const uint8_t DIR_PIN  = 11;

IntervalTimer stepTimer;

// state for toggling
volatile bool stepState = false;
volatile uint32_t stepCount = 0;

// Desired step frequency (steps per second)
volatile float steps_per_sec = 500.0f; // exemple
// Timer frequency = 2 * steps_per_sec
volatile float timerFreq = steps_per_sec * 2.0f;

// ISR called at timerFreq Hz: toggles STEP pin
void onStepTimer() {
  stepState = !stepState;
  digitalWriteFast(STEP_PIN, stepState ? HIGH : LOW);

  // Count a full step on rising edge (when stepState == true)
  if (stepState) {
    stepCount++;
  }
}

void setStepsPerSec(float sps) {
  if (sps < 0.1f) sps = 0.1f;
  steps_per_sec = sps;
  timerFreq = steps_per_sec * 2.0f;
  // reconfigure timer: stop, begin with new period (in microseconds)
  stepTimer.end();
  // period in microseconds = 1e6 / timerFreq
  float period_us = 1e6f / timerFreq;
  stepTimer.begin(onStepTimer, (uint32_t)period_us);
}

void setup() {
  Serial.begin(115200);
  delay(200);
  Serial.println("DRV8825 simple test (microstep x32)");

  pinMode(STEP_PIN, OUTPUT);
  pinMode(DIR_PIN, OUTPUT);

  // default direction
  digitalWrite(DIR_PIN, HIGH);

  // start timer
  setStepsPerSec(steps_per_sec);

  Serial.print("Initial steps/s = ");
  Serial.println(steps_per_sec);
}

unsigned long lastPrint = 0;
void loop() {
  // simple serial commands to control:
  // "SPS=1000" -> set steps per second
  // "DIR=0" or "DIR=1" -> set direction
  if (Serial.available()) {
    String cmd = Serial.readStringUntil('\n');
    cmd.trim();
    if (cmd.startsWith("SPS=")) {
      float v = cmd.substring(4).toFloat();
      setStepsPerSec(v);
      Serial.print("Set steps_per_sec = ");
      Serial.println(v);
    } else if (cmd.startsWith("DIR=")) {
      int d = cmd.substring(4).toInt();
      digitalWrite(DIR_PIN, d ? HIGH : LOW);
      Serial.print("Set DIR = ");
      Serial.println(d);
    } else if (cmd == "STOP") {
      stepTimer.end();
      Serial.println("Timer stopped -> motor idle.");
    } else if (cmd == "START") {
      setStepsPerSec(steps_per_sec);
      Serial.println("Timer started.");
    } else if (cmd == "COUNT") {
      Serial.print("Step count = ");
      Serial.println(stepCount);
    } else {
      Serial.println("Unknown command. Use SPS=..., DIR=0/1, START/STOP, COUNT");
    }
  }

  // periodic status output
  if (millis() - lastPrint > 500) {
    lastPrint = millis();
    Serial.print("SPS=");
    Serial.print(steps_per_sec);
    Serial.print("  DIR=");
    Serial.print(digitalRead(DIR_PIN));
    Serial.print("  Count=");
    Serial.println(stepCount);
  }
}

// #include <Arduino.h>
// #include <IntervalTimer.h>

// // ==========================
// // PID Parameters (modifiable via USB)
// // ==========================
// volatile float Kp = 5.0f;
// volatile float Ki = 0.0f;
// volatile float Kd = 0.0f;
// volatile float setpoint = 0.0f;

// // ==========================
// // Simulated system
// // ==========================
// // Simulated encoder position (rad)
// volatile float position = 0.0f;
// // Simulated velocity (rad/s)
// volatile float velocity = 0.0f;

// // PID internal
// volatile float integral = 0.0f;
// volatile float lastError = 0.0f;

// // Timer for 1 kHz loop
// IntervalTimer pidTimer;

// // Limit loop frequency of streaming
// unsigned long lastStream = 0;

// // ============================================
// // 1 kHz CONTROL LOOP
// // ============================================
// void pidISR() {
//     float dt = 0.001f;  // 1 ms

//     // ---- Simulated system dynamics ----
//     // Very basic first-order model:
//     // velocity += (command - damping*velocity) * dt
//     // position += velocity * dt

//     // Here command = PID output
//     // (We'll compute PID output below)

//     // ---- PID ----
//     float error = setpoint - position;

//     integral += error * dt;
//     float derivative = (error - lastError) / dt;

//     float command = Kp * error + Ki * integral + Kd * derivative;
//     lastError = error;

//     // ---- UPDATE SIMULATED SYSTEM ----
//     float damping = 0.2f;     // Make the system stable-ish
//     velocity += (command - damping * velocity) * dt;
//     position += velocity * dt;

//     // That's it. A tiny physics engine :)
// }

// // ============================================
// // Parse serial commands
// // Ex: "P=12.3", "I=0.1", "D=2.0", "S=1.57"
// // ============================================
// void parseCommand(String cmd) {
//     cmd.trim();
//     if (cmd.startsWith("P=")) {
//         Kp = cmd.substring(2).toFloat();
//     } else if (cmd.startsWith("I=")) {
//         Ki = cmd.substring(2).toFloat();
//     } else if (cmd.startsWith("D=")) {
//         Kd = cmd.substring(2).toFloat();
//     } else if (cmd.startsWith("S=")) {
//         setpoint = cmd.substring(2).toFloat();
//     }

//     Serial.print("Updated -> Kp=");
//     Serial.print(Kp);
//     Serial.print(" Ki=");
//     Serial.print(Ki);
//     Serial.print(" Kd=");
//     Serial.print(Kd);
//     Serial.print(" Setpoint=");
//     Serial.println(setpoint);
// }

// // ============================================
// // SETUP
// // ============================================
// void setup() {
//     Serial.begin(115200);
//     delay(1000);

//     Serial.println("Starting simulation...");

//     pidTimer.begin(pidISR, 1000);  // 1 kHz
// }

// // ============================================
// // MAIN LOOP
// // ============================================
// void loop() {
//     // Handle incoming USB commands
//     if (Serial.available()) {
//         String cmd = Serial.readStringUntil('\n');
//         parseCommand(cmd);
//     }

//     // Stream data @ 50 Hz
//     if (millis() - lastStream > 20) {
//         lastStream = millis();
//         Serial.print("POS=");
//         Serial.print(position, 6);
//         Serial.print(" VEL=");
//         Serial.print(velocity, 6);
//         Serial.print(" SP=");
//         Serial.println(setpoint, 3);
//     }
// }

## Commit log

2026-03-05 Initial commit: inverted pendulum simulation, GUI, and firmware
    Add Python control simulation (model/), PyQt5 hardware GUI (gui/),
    and Teensy 4.1 firmware (teensy/). Visualization saves figures to
    figs/ instead of blocking with plt.show(). Includes CLAUDE.md and
    .gitignore.
    [main.cpp, main_motor.cpp, program.py]
2026-03-05 Update model to match hand-derived equations and rework snapshots
    - Fix dynamics and linearization: use I_com = 1/12*m*l² (uniform rod),
    denominator D = I + m*l² throughout, correct sign of B[3,0]
    - Adopt theta=0 (down) / theta=pi (up) convention with phi = theta - pi
    as the linearization variable; update PID and LQR controllers accordingly
    - Fix pendulum tip coordinates in visualizations (py = -l*cos(theta))
    - Rewrite plot_snapshots as a single shared-axis figure where the x-axis
    maps to physical cart position; snapshots colored by time via plasma colormap
2026-03-05 Add telemetry capture script for free-response measurement
    tools/capture.py connects to the Teensy over serial, decodes the binary
    packet stream, and saves angle/cart/velocity data to CSV. Intended for
    measuring the pendulum's free (stable) response to fit model parameters.
2026-03-05 Fix capture.py hanging after plot: save PNG and exit cleanly
    Replaced plt.show() (which blocks on the Tk mainloop) with plt.close().
    The script now terminates as soon as the PNG is saved.
    [capture.py]
2026-03-05 Fix inertia formula: I_com = 1/12 * m * (2l)^2 for uniform rod
    l is the pivot-to-CoM distance (half total length), so the full rod
    length is 2l, giving I = 1/12 * m * (2l)^2 = 1/3 * m * l^2.
2026-03-05 Add parameter fitting script for free-response data
    tools/fit.py fits l and c to a captured CSV using the nonlinear pendulum
    ODE (fixed cart, u=0). Starts from the first peak (clean initial condition:
    θ₀ = peak amplitude, ω₀ = 0). Uses Nelder-Mead via scipy.optimize and
    reports l, c, ω_n, ζ and RMS error, then saves a comparison plot to figs/.
    [fit.py]
2026-03-05 Validate P-controller stability threshold with two simulations
    Replaces __main__ example with a Kp validation: computes the critical
    proportional gain kp_crit = c²/(4·m·l·(I+m·l²)) + g from fitted
    parameters, then simulates ±20% around it. Saves figs/kp_below.png
    (unstable, pendulum falls) and figs/kp_above.png (stable, oscillates
    to upright). Cart drift in the stable case confirms P-only has no
    position integral.
2026-03-05 Rework firmware: acceleration-based P/PD/LQR control, safety limits, LP filter
    - Plant input changed to cart acceleration [m/s²], integrated to velocity in ISR
    - Implement P, PD, and LQR controller modes (SI units throughout)
    - LQR gains sent as 4-vector: SET K k0 k1 k2 k3 [x, x_dot, phi, phi_dot]
    - Setpoints: SET THETA <deg>, SET X <mm>
    - Safety: hard stop at ±200 mm (stops cart, disengages feedback, keeps motor on)
    - Soft limit at ±160 mm blocks acceleration toward boundary
    - Velocity limit 300 mm/s, acceleration limit 10 000 mm/s²
    - Angular velocity: finite difference + 50 Hz first-order IIR (α = 0.7304)
    - Telemetry: 27-byte packed struct with pend_vel_deg_s and accel_cmd_mm_s2
    - Fix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
    [main.cpp]
2026-03-05 Rework GUI: structured layout, P/PD/LQR panels, homing, color-coded buttons
    - Structured layout: plots left (3/4), control panels right (1/4)
    - Controller panel: mode selector (P/PD/LQR), Kp/Kd spinboxes (±10 000),
    LQR K vector inputs; sends gains to Teensy on Apply
    - Setpoints panel: θ_ref [deg] and x_ref [mm]
    - Motor control panel: Motor/Feedback toggle buttons (green=ON, red=OFF),
    Zero Cart, Zero Encoder, open-loop velocity slider, Go to Zero button (50 mm/s)
    - Angle center selector: 0° (downward) or 180° (upright) subtracts offset
    - Data panel: Save CSV with all 8 telemetry columns
    - Create QApplication before importing pyqtgraph to prevent core dump
    - Display window: 10 s rollin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
    [program.py]
2026-03-05 Model: add LQGController, named LQR figures, French labels, update params to 100g
    Controllers:
    - Add LQGController: Kalman filter (LQE via dual LQR) + LQR state feedback
    Observes x and phi; continuous observer discretised with Euler at dt
    - LQRController unchanged
    Simulations (__main__):
    - All figure labels, titles, and axes in French
    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
2026-03-05 Add mechanical design files: FreeCAD sources and STL exports
    - FreeCAD source files: encoder support, motor support, belt support,
    pendulum (small), V-slot profile, 3mm spacer, full assembly
    - STL exports: encoder_support, motor_support, support_courroie,
    pendulum variants (100/200/300mm), 3mm_spacer
    [3mm_space.FCStd, 3mm_spacer.stl, encoder_support.FCStd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]
2026-03-06 Model: update figure generation for presentation
    - openloop_175deg: use original params, clip to 1s, asymmetric ylim (-50, +10)°
    - kp_below: clip to 3s, ylim (0, 60)°; all kp figures use original 30g params
    - LQR: loop over two ponderation sets (q_x=100/q_φ=1 and q_x=1/q_φ=100)
    - LQR figures: half-linewidth (5×5), shared ylims ±5° and -200/+50 mm
2026-03-06 Tools: extend plot_experiment.py options, add plot_stability.py
    plot_experiment.py: add --all, --ylim-x, --ylim-phi, --detrend-x,
    --no-shading, --margin-after options; green shading for all feedback_on
    spans; remove suptitle
    plot_stability.py: new script to visualize closed-loop stability from
    last N seconds of a CSV recording
    [plot_experiment.py, plot_stability.py]
2026-03-08 Presentation: update slides, figures, and add backup code slides
    Slides:
    - 2_dynamique: animate linearisation slide (left then right column);
    animate comparaison slide (data first, then fit + tikz blocks)
    - 3_control_pid: split experimental results into phi/x with uncover,
    add simulation snapshot slide (step 3)
    - 4_control_lqr: fill in Choix de K slide (Riccati equation, J criterion,
    numerical example); fill in Simulation slide (two-column LQR comparison)
    - 5_conclusion: write conclusion (PD vs LQR summary, LQG/MPC perspectives);
    add 3 backup code slides (fit.py, simulation, Teensy firmware)
    Figures: regenerated with correct phi reference, split phi/x,
    half-width sizing, larger fo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
2026-03-09 Docs: add system schematic and demo videos to README
2026-03-22 Presentation: update slides and add experiment photos
    - Résultats expérimentaux (PD): restructure into 8 steps — plots, then
    photos (pd_control_01–05, cropped 10% top/bottom), then simulation
    - LQR equivalence backup slide: TikZ diagram showing LQR as dual PD
    - Add LQR closer-view photos (lqr_control_01–05)
    - Update system schematic figure
